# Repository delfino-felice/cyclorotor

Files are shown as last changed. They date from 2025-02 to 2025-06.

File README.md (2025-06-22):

# cyclocopter

This project aims to build a tricopter powered by two cyclorotors and one traditional propeller. Yaw control is managed through a servo mechanism that adjusts the orientation of the third motor. The primary goal is to explore alternative propulsion technologies for small UAVs by integrating cycloidal rotor mechanics into a simplified multicopter design.

The vehicle is almost entirely 3D-printed, excluding standard components such as motors, screws, and wiring. Lightweight PLA (LW-PLA) was selected as the primary material to minimize overall mass—critical for aerial vehicles—while standard PLA was used selectively in structural areas where greater strength and rigidity are required.

## Structure

The drone's structure is based on a carbon fiber tube with a 12 mm diameter and approximately 50 cm in length, chosen for its lightweight and rigid properties. At each end of the tube, a cyclorotor assembly is mounted using dual bearings for smooth and reliable rotation. These cyclorotors provide the primary lift and assist in directional thrust.

A 3D-printed clamp is positioned at the center of the tube, acting as the core structural node. It integrates and supports:

- The flight battery: 2700mAh 3s1p LiPo
- Power distribution board (PDB)
- Flight controller: F7
- Cyclorotor motors with a belt tensioning system (see photos)
- A pivoting mount and rotating joint for the rear motor, which consists of a traditional propeller attached to a servo-actuated joint. This setup provides additional thrust and enables yaw control (see photos).

## Electronics

The electronic subsystem provides stable power distribution, motor control, flight assistance (stabilization, altitude hold), and control signal routing. It includes:

- A LiPo battery connected to a Power Distribution Board (PDB)
- Brushless motors: two A2212 for the cyclorotors and one A2208 for the traditional propeller
- 30A ESCs to drive all motors
- An F7-based flight controller for real-time stabilization and control
- An Arduino-based radio receiver is used for manual remote operation. While it does not match the signal range of dedicated radio systems, it remains a cost-effective option for simple startup procedures and hovering tests.
- A servo for yaw control linked to the third motor mount

## Things to Do

Tasks that must be completed before MFR2025 and have already been thoroughly analyzed:

- Integration of the flight controller and radio receiver
- fly

## Future Ideas

Concepts for potential future upgrades, pending further analysis and decision:

- Autonomous flight capabilities: path following (e.g., with ArduPilot) and collision avoidance — key features for exploring future urban air mobility
- Larger or additional wings to increase lift capabilities and enable transportation of heavier payloads, potentially leading to a dedicated cargo version
- Thrust vectoring control (TVC) for the cyclorotors to unlock the full potential of this propulsion method
- Advanced linkage systems, such as the track-guided variable pitch mechanism seen in other experimental prototypes, which could simplify the addition of more blades and allow for higher rotational speeds, thus increasing thrust
- Build guide

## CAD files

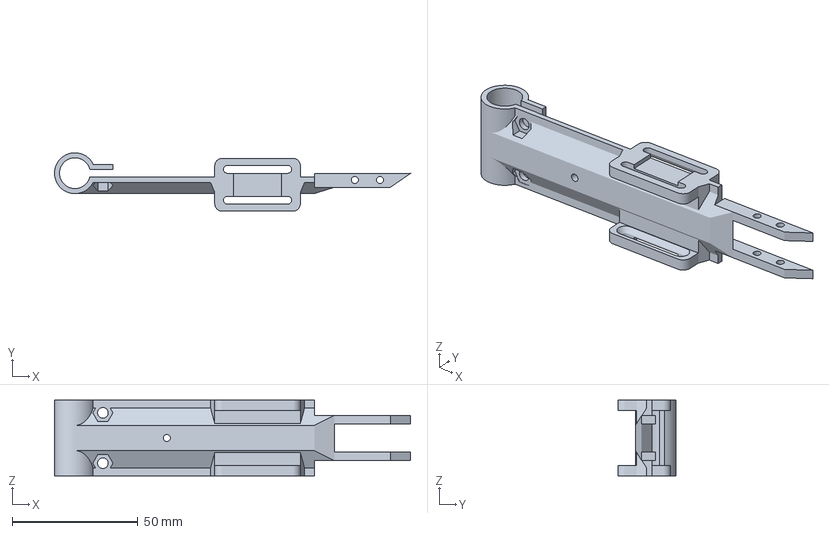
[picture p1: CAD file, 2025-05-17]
stl/3mf/main structure.3mf
141.3 x 23.2 x 30.0 mm

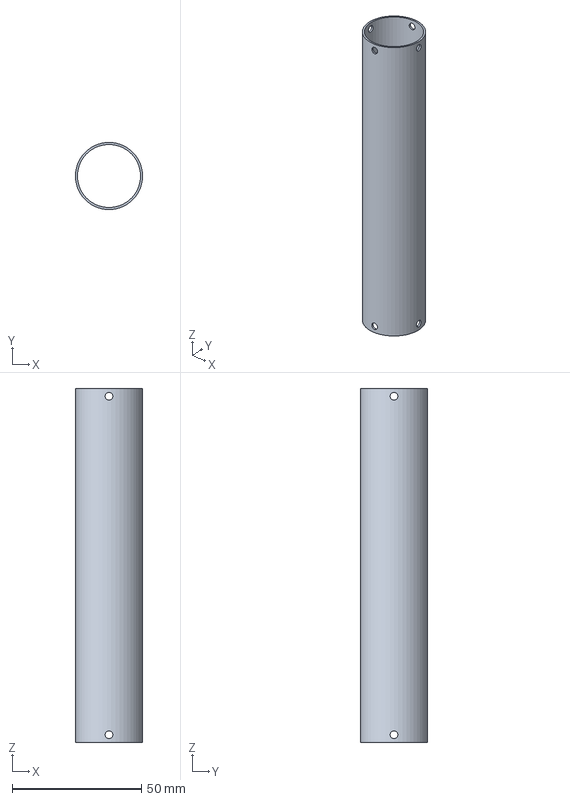
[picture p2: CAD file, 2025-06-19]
stl/3mf/tubo.3mf
26.0 x 25.9 x 137.0 mm

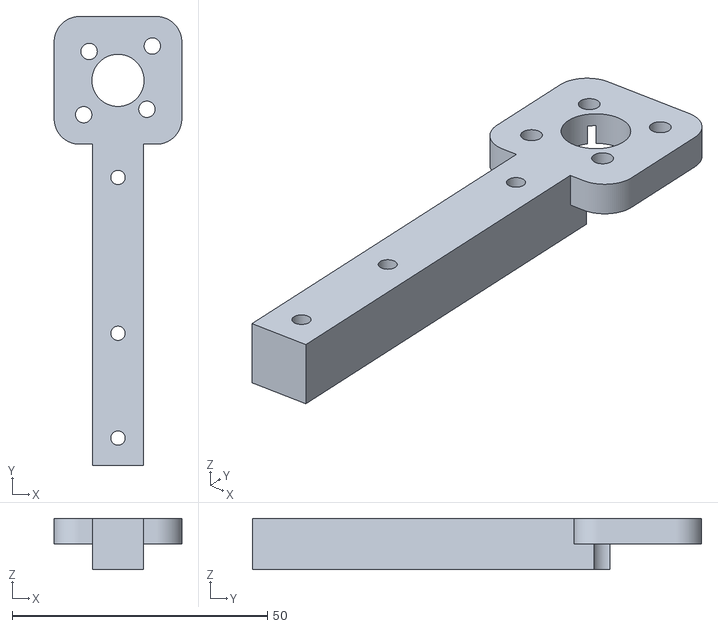
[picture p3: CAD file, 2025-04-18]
stl/giunto rotante/motor_mount.stl
25.0 x 87.9 x 10.0

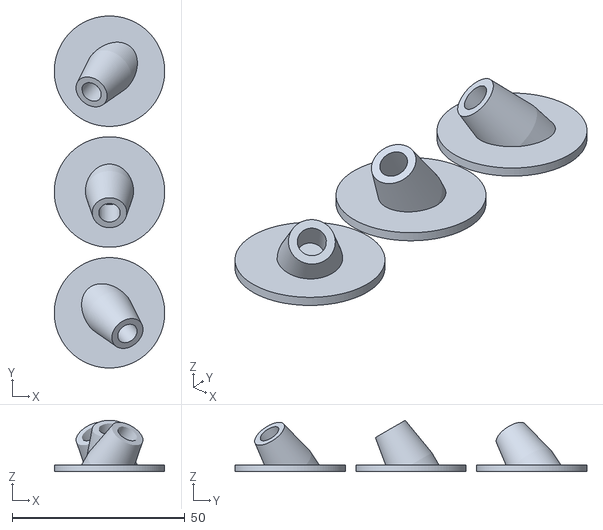
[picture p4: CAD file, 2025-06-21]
stl/piedi.stl
32.0 x 102.0 x 14.9

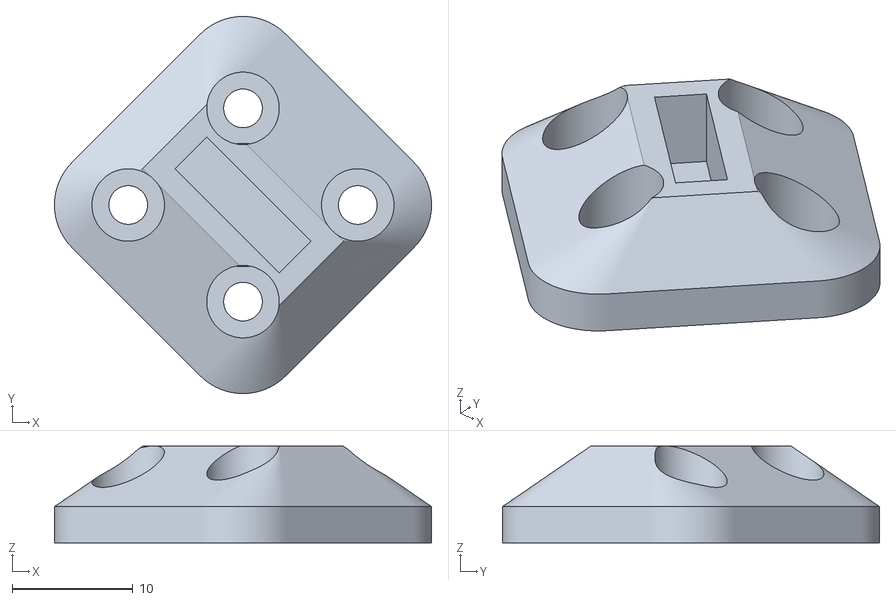
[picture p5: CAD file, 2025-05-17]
stl/test/supporto motore.stl
31.2 x 31.2 x 8.00

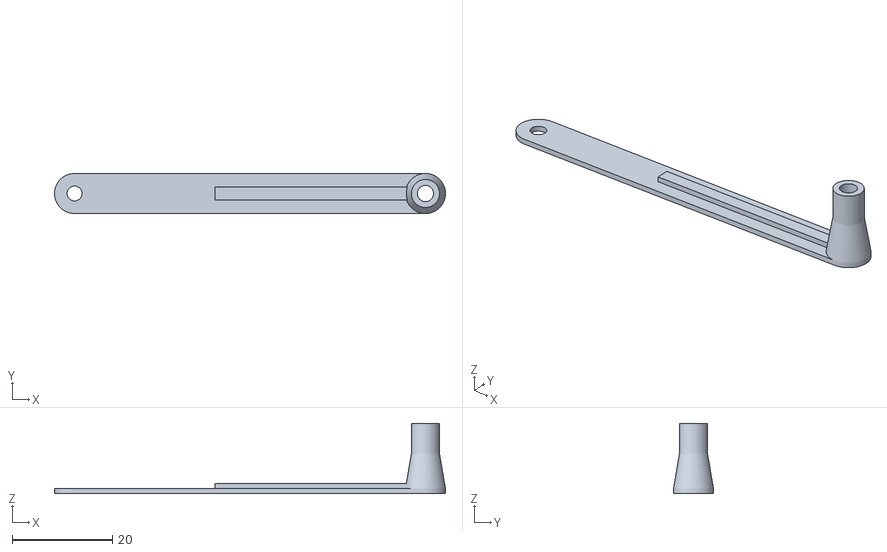
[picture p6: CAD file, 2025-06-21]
stl/braccio.stl
78.0 x 8.00 x 14.0

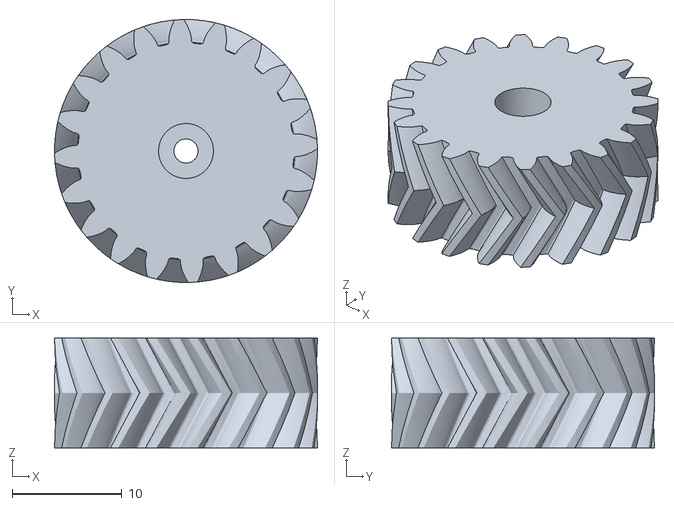
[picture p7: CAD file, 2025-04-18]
stl/giunto rotante/servo_gear.stl
24.0 x 24.0 x 10.0

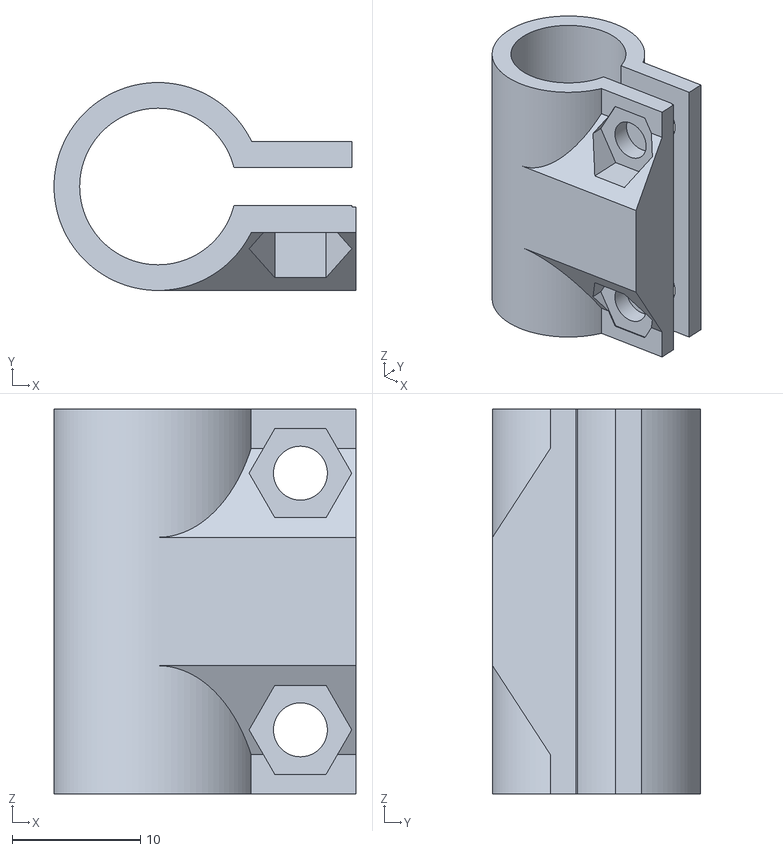
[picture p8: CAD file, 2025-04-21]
stl/test/clamp.stl
23.5 x 16.2 x 30.0

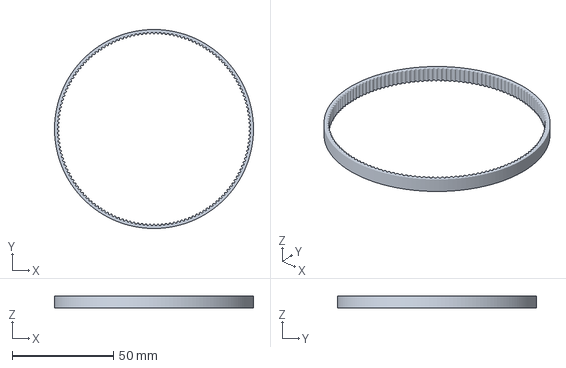
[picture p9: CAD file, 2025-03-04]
stl/3mf/belt.3mf
98.3 x 98.3 x 6.00 mm

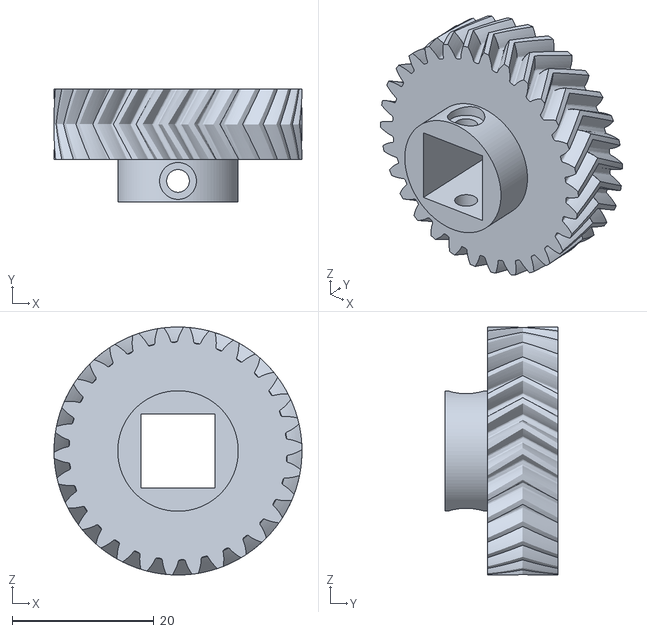
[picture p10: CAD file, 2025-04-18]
stl/giunto rotante/gear.stl
35.0 x 16.0 x 35.0

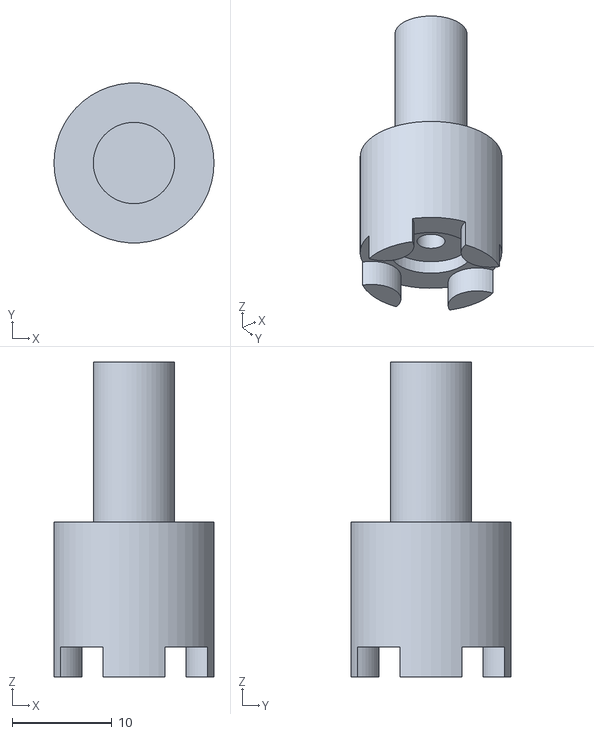
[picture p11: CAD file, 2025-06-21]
stl/ruota piccola.stl
16.0 x 16.0 x 31.5

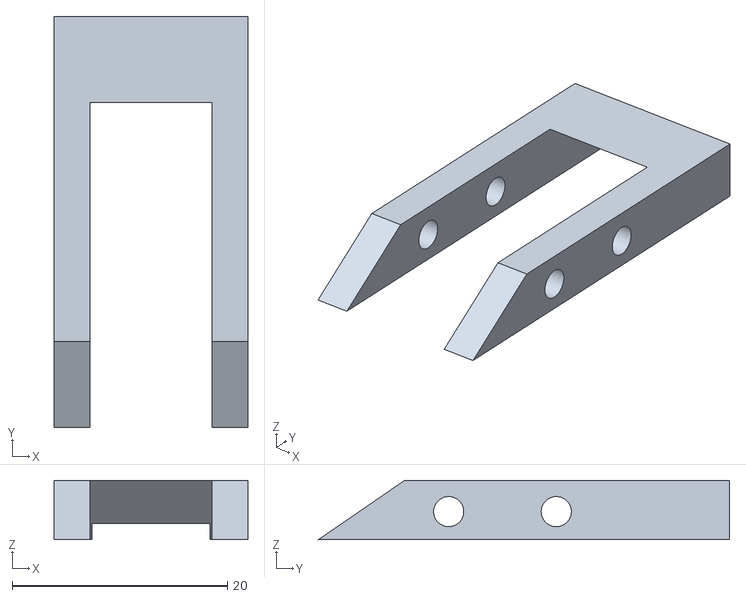
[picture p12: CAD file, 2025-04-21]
stl/test/attacco giunto.stl
18.0 x 38.2 x 5.50

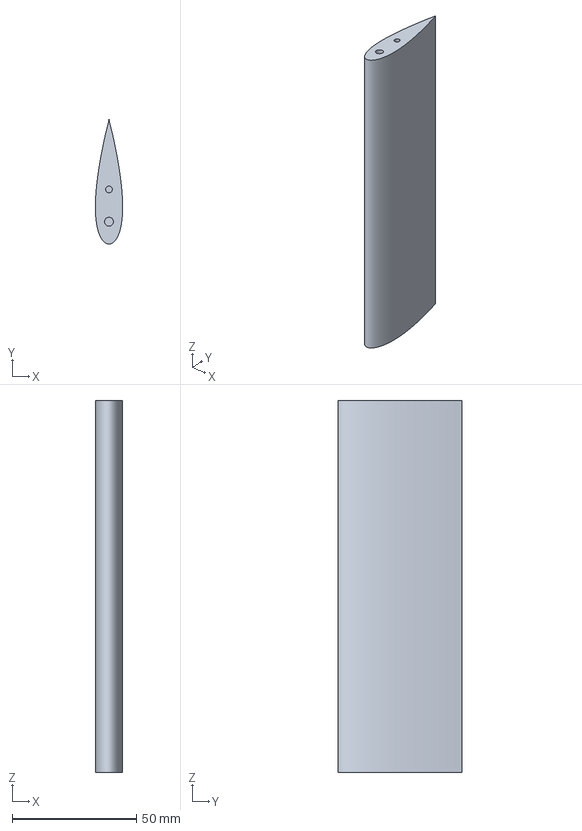
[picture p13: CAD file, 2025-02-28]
stl/3mf/wing.3mf
11.0 x 50.0 x 150.0 mm

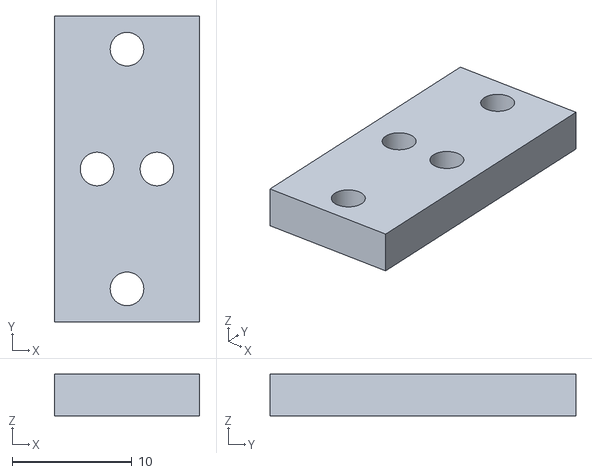
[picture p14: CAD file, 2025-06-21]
stl/asse motori.stl
12.1 x 25.5 x 3.50

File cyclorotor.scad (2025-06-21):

include <libraries/BOSL2/std.scad>
include <libraries\parametricPulley.scad>
use <libraries/NACA/ShortCuts.scad>
use <libraries/NACA/Naca4.scad>

$fn=50;

n=120; // numero denti ruota grande
or = ((n*2)/(3.14159265*2)-0.254);


module braccio() {
H=14; //altezza cilindro 
diff("remove") {
    cuboid([78,8,1], anchor=BOT, rounding=4,edges=[BACK+RIGHT,BACK+LEFT,FWD+RIGHT,FWD+LEFT])
        attach(UP,UP, align=RIGHT, inset=1) cube([45,2.5,1]);

    translate([35,0,]) cylinder(r=2.8, h=H, anchor=BOT); 
 
    translate([35,0,0]) cylinder(r=1.62, h=100, $tag="remove", center=true); // foro ala
    translate([-35,0,0]) cylinder(r=1.49, h=100, $tag="remove", center=true); // foro mozzo centrale    
    right(35) up(1) cylinder(r1=4, r2=2.8, h=7, anchor=BOT); 
}}

module clip () {

H=8;
IR=6.1;
x=7; // spessore supporti viti
difference() {
    union() {
        cylinder(h=H, r=IR+1.6, center=true); // cilindro centrale
        translate([IR+3.6,0,0]) cube([7,x,H], center=true); // supporto per viti
        yrot(90) prismoid(size1=[H,IR*2+3.2], size2=[H,x], h=IR+7.7);
    }
    union() {
        translate ([IR+3.6,0,0]) rotate ([90,0,0]) cylinder(r=1.65,h=6, center=true) {
            attach(UP,UP) cylinder(r=2.7, h=10, center=true);
            zrot(90) attach(BOT,UP) cylinder(r=3.3, h=10, $fn=6, center=true);
        }; // foro vite
        translate ([IR+3.2,0,0]) cube([10,2,200], center=true); // gioco dimensione foro centrale       
        cylinder(r=IR, h=H, center=true);
    }
}}

module distanziatore () {
tube(ir=1.8, wall=2, h=6);
}

module frame() {
l1=10;
l2=5;
w=20;
h=10;
diff("remove") {
    union() {
        // bracci della croce
        cuboid([150,10,3], rounding=5,edges=[BACK+RIGHT,BACK+LEFT,FWD+RIGHT,FWD+LEFT], anchor=BOT);
        rotate([0, 0, 90]) {
            cuboid([150,10,3], rounding=5,edges=[BACK+RIGHT,BACK+LEFT,FWD+RIGHT,FWD+LEFT], anchor=BOT);
        }
        // centro
        cylinder(r=16.2, h=10.5, anchor=BOT) // supporto cuscinetto
            attach(UP,BOT) cylinder(r1=16.2, r2=14.5, h=6) // supporto tubo
                attach(UP,UP, inside=true) cylinder(r=13.2,h=6,$tag="remove") { // foro tubo
                    // fori viti tubo
                    attach([1,1,0],BOT, overlap=.15) cylinder(r=1.6,h=1.5, $tag="remove") attach(UP,UP) cylinder(r=2.7, h=10);
                    attach([1,-1,0],BOT, overlap=.15) cylinder(r=1.6,h=1.5, $tag="remove") attach(UP,UP) cylinder(r=2.7, h=10);
                    attach([-1,1,0],BOT, overlap=.15) cylinder(r=1.6,h=1.5, $tag="remove") attach(UP,UP) cylinder(r=2.7, h=10);
                    attach([-1,-1,0],BOT, overlap=.15) cylinder(r=1.6,h=1.5, $tag="remove") attach(UP,UP) cylinder(r=2.7, h=10);
                    // conifere
                    attach(BOT,BOT) cylinder(r1=11, r2=14.15, h=2.5);
                }; 
        // interfacce supporto-bracci
        translate([15,0,3]) rotate([0,0,90]) prismoid(size1=[l1,w], size2=[l2,0], shift=[0,w/2+0], h=h, anchor=BOT+BACK);
        translate([0,15,3]) rotate([0,0,180]) prismoid(size1=[l1,w], size2=[l2,0], shift=[0,w/2+0], h=h, anchor=BOT+BACK);
        translate([-15,0,3]) rotate([0,0,270]) prismoid(size1=[l1,w], size2=[l2,0], shift=[0,w/2+0], h=h, anchor=BOT+BACK);
        translate([0,-15,3]) rotate([0,0,0]) prismoid(size1=[l1,w], size2=[l2,0], shift=[0,w/2+0], h=h, anchor=BOT+BACK);

    }
    tag("remove") {
        // fori viti ali
        translate([70,0,0]) cylinder(r=2.2, h=10, center=true); 
        translate([-70,0,0]) cylinder(r=2.2, h=10, center=true); 
        translate([0,70,0]) cylinder(r=2.2, h=10, center=true); 
        translate([0,-70,0]) cylinder(r=2.2, h=10, center=true); 
        // supporto cuscinetto
        cylinder(r=14.15, h=8, anchor=BOT);
        cylinder(r=11, h=100, center=true);
        // fori viti ingranaggio
        translate([or-8,0,0]) cylinder(r=1.4, h=100, center=true);
        translate([-(or-8),0,0]) cylinder(r=1.4, h=100, center=true);
        translate([0,or-8,0]) cylinder(r=1.4, h=100, center=true);
        translate([0,-(or-8),0]) cylinder(r=1.4, h=100, center=true);
    }    
}
echo(str("or = ", or));
}

module tubo() {
h=136;  
diff("remove") {
tube(od=26, wall=0.8, h=h);
up(h/2-3) cylinder(r=1.5, h=100, orient=FWD, center=true, $tag="remove");
up(h/2-3) cylinder(r=1.5, h=100, orient=LEFT, center=true, $tag="remove");

down(h/2-3) cylinder(r=1.5, h=100, orient=FWD, center=true, $tag="remove");
down(h/2-3) cylinder(r=1.5, h=100, orient=LEFT, center=true, $tag="remove");

}}

module ruota_grande() {    
h=7;
gear(number_of_teeth=n, profile=12, motor_shaft_diameter=(or*2)-8, belt_retainer=1, retainer_height_p=1.5, belt_idler=1, idler_height_p=1.5,base_height=0,base_diameter=17.4,flange_option=0);
// attacchi viti
difference() {
    union() {
        translate([or-7,0,0]) rotate([0,0,0]) cuboid([9,8,3], rounding=2.2,edges=[BACK+RIGHT,BACK+LEFT,FWD+RIGHT,FWD+LEFT], anchor=BOT);
        translate([-(or-7),0,0]) rotate([0,0,0]) cuboid([9,8,3], rounding=2.2,edges=[BACK+RIGHT,BACK+LEFT,FWD+RIGHT,FWD+LEFT], anchor=BOT);
        translate([0,or-7,0]) rotate([0,0,90]) cuboid([9,8,3], rounding=2.2,edges=[BACK+RIGHT,BACK+LEFT,FWD+RIGHT,FWD+LEFT], anchor=BOT);
        translate([0,-(or-7),0]) rotate([0,0,90]) cuboid([9,8,3], rounding=2.2,edges=[BACK+RIGHT,BACK+LEFT,FWD+RIGHT,FWD+LEFT], anchor=BOT);
    }
    union() {
        translate([or-8,0,0]) cylinder(r=1.6, h=100, center=true);
        translate([-(or-8),0,0]) cylinder(r=1.6, h=100, center=true);
        translate([0,or-8,0]) cylinder(r=1.6, h=100, center=true);
        translate([0,-(or-8),0]) cylinder(r=1.6, h=100, center=true);
    }
}}

module ruota_piccola() {
s=8; // raggio cilindrico negativo esterno
diff("remove"){
cylinder(r=4.07, h=16, anchor=BOT);
cylinder(r=s, h=12.5, anchor=UP){
    attach(BOT,UP, inside=true) cylinder(r=4.6, h=1.5)
        attach(BOT,BOT) cylinder(r=1.58, h=15);

    attach(BOT,UP) fwd(8.5) cylinder(r=3.3, h=3);
    attach(BOT,UP) back(8.5) cylinder(r=3.3, h=3);
    attach(BOT,UP) left(8.5) cylinder(r=3.3, h=3);
    attach(BOT,UP) right(8.5) cylinder(r=3.3, h=3);

};
tube(ir=s, wall=20, h=100, $tag="remove");
}}

module supporto_bracci() {
H=6;
R1=1.3;
R2=6.1;
D=9.5;
x=7; // spessore supporti viti
diff("remove") {
    rotate([0,90,0]) prismoid(size1=[H,(R2+1.6)*2], size2=[H,(R1+1.6)*2], h=D) { // interspazio
        position(UP) rotate([0,90,0]) cylinder(r=R1+1.6, h=H, center=true) // cilindro minore
            attach(BOT,BOT, inside=true) cylinder(r=R1, h=H, $tag="remove", center=true); // foro minore
        position(DOWN) rotate([0,90,0]) cylinder(r=R2+1.6, h=H, center=true)  // cilindro maggiore
            attach(UP,BOT, inside=true) cylinder(r=R2, h=H-0.5, $tag="remove"); // foro maggiore con bordo
    }
    translate([-(R2+3.6),0,0]) cube([7,x,H], center=true); // supporto per viti        
    yrot(-90) prismoid(size1=[H,R2*2+3.2], size2=[H,x], h=R2+7.7);


    tag("remove") {
        cylinder(r=R2-0.7, h=H+1, center=true); // foro maggiore
        translate ([-R2-3.6,0,0]) rotate ([90,0,0]) cylinder(r=1.65,h=6, center=true) {
            attach(UP,UP) cylinder(r=2.7, h=10, center=true);
            attach(BOT,UP) cylinder(r=3.3, h=10, $fn=6, center=true);
        }; // foro vite 
        translate([-(R2+3.6),0,0]) cube([10,2,100], center=true); // gioco viti        
    }

}}

module wing() {

difference() {
    airfoil(naca = 0022, L = 50, N=1000, h = 150, open = false); 
    union() {
        translate([9,0,0]) cylinder(r=1.8, h=24, center=true);
        translate([22,0,0]) cylinder(r=1.35, h=24, center=true);

        translate([9,0,150]) cylinder(r=1.8, h=24, center=true);
        translate([22,0,150]) cylinder(r=1.35, h=24, center=true);
    }    
}}

// module call
braccio();
//clip();
//distanziatore();
//frame();
//ruota_grande();
//ruota_piccola();
//supporto_bracci();
//wing();
//tubo();

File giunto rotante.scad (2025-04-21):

include <libraries/BOSL2/std.scad>
include <libraries/BOSL2/gears.scad>

// TO DO //
// ruota leggermente più basso dal motore
// controllare fori per cuscinetto accanto al motore


$fn=100;

module servo_gear() {
circ_pitch=3;
teeth=20;
diff ("remove") {
import("STL/11_Gripper_gear_v4.stl");
spur_gear(
    circ_pitch=circ_pitch, teeth=teeth, thickness=10, shaft_diam=5,
    helical=30, herringbone=true, slices=5, anchor=BOT
);

echo(str("pitch_radius = ", pitch_radius(circ_pitch, teeth,30)));
echo(str("outer_radius = ", outer_radius(circ_pitch, teeth,30)));

}}

module motor_mount () {
legth=55;

diff("remove") {
zrot(45) {
cuboid([25,25,5], anchor=BOT, spin=45, rounding=5, edges=[FRONT+LEFT,FRONT+RIGHT,BACK+LEFT,BACK+RIGHT]);
translate([-3.8,3.8,0]) cube([10,legth+15,10], anchor=FRONT+BOT, spin=45);
tag("remove") {
    fwd(8) cylinder(r=1.6, h=2, anchor=BOT) attach(UP,BOT) cylinder(r=3, h=10);
    back(8) cylinder(r=1.6, h=2, anchor=BOT) attach(UP,BOT) cylinder(r=3, h=10);
    left(9.5) cylinder(r=1.6, h=2, anchor=BOT) attach(UP,BOT) cylinder(r=3, h=10);
    right(9.5) cylinder(r=1.6, h=2, anchor=BOT) attach(UP,BOT) cylinder(r=3, h=10);
    cylinder(r=5.1, h=100, center=true);
}}
left(19) cylinder(r=1.4, h=10,anchor=BOT, $tag="remove");
left(49.5) cylinder(r=1.4, h=10,anchor=BOT, $tag="remove");
left(70) cylinder(r=1.4, h=10,anchor=BOT, $tag="remove");
}}

module giunto() {
thickness=4;
ir=16.1;
d=26;
diff("remove") {
tube(ir=ir, wall=thickness, h=d, orient=FWD) {
    attach(UP, BOT) cylinder(r=ir+thickness, h=10, orient=FWD, $tag="bau") {
        cyl(r=ir, h=10, $tag="remove");
        attach(UP,UP, inside=true) tube(ir=ir-4, or=ir+thickness, h=1, anchor=BOT, $tag="keep");
        
        attach([1,0.5,0], FRONT, overlap=2) cube([33,15,10], $tag="bau") {
            attach(BACK,FRONT,inside=true) cube([22.8,12.2,10], $tag="remove") {
                attach(UP,UP, align=LEFT, inside=true) right(3.5) cylinder(r=0.9, h=10, $tag="remove");                      
                attach(UP,UP, align=RIGHT, inside=true) left(3.5) cylinder(r=0.9, h=10, $tag="remove");
            };
        };
        
        attach([-1,0.5,0], FRONT, overlap=2) cube([33,15,10], $tag="bau") {
            attach(BACK,FRONT,inside=true) cube([22.8,12.2,10], $tag="remove") {
                attach(UP,UP, align=LEFT, inside=true) right(3.5) cylinder(r=0.9, h=10, $tag="remove");                      
                attach(UP,UP, align=RIGHT, inside=true) left(3.5) cylinder(r=0.9, h=10, $tag="remove");
            };
        };
    };
    attach(BOT, UP) cylinder(r=ir+thickness, h=10, orient=FWD, $tag="bau") {
        cyl(r=ir, h=10, $tag="remove");
        attach(UP,UP, inside=true) tube(ir=ir-4, or=ir+thickness, h=1, anchor=BOT, $tag="keep");
    };

    attach (BACK,FRONT, inside=true) cube([(ir+thickness)*2,30,d]);
    
    diff ("e") {
        attach (FRONT, BOT, overlap=2) prismoid(size1=[15,d+20], size2=[15,d-5], h=9) {
            attach(LEFT, LEFT, inside=true) fwd(2) right(2) prismoid(size1=[2,d+22], size2=[2,d-3], h=9, $tag="e");
            attach(RIGHT, LEFT, inside=true) fwd(2) left(2) prismoid(size1=[2,d+22], size2=[2,d-3], h=9, $tag="e");

            fwd(5) cylinder(r=1.4, h=15, orient=LEFT, anchor=CENTRE, $tag="e");
            back(5) cylinder(r=1.4, h=15, orient=LEFT, anchor=CENTRE, $tag="e");

        };
    }

};

cylinder(r=18, h=26, orient=BACK, anchor=CENTRE, $tag="remove");    
}
}

module bearing () {
diff("remove") {

import("STL/Bearing_6002_V02_tolMin (base).stl");
cylinder(r=8.5, h=15);
cube([10.4,10.4,100],anchor=BOT, $tag="remove");
translate([-5,0,12]) cylinder(r=1.6, h=2, orient=LEFT,$tag="remove" )
    attach(UP,UP) cylinder(r=2.6, h=10);
translate([5,0,12]) cylinder(r=1.6, h=2, orient=RIGHT,$tag="remove" )
    attach(UP,UP) cylinder(r=2.6, h=10);
}
}

module gear() {
circ_pitch=3;
teeth=30;
diff("remove") {
spur_gear(
    circ_pitch=circ_pitch, teeth=teeth, thickness=10, shaft_diam=8.5,
    helical=30, herringbone=true, slices=5, anchor=BOT
);
;
echo(str("pitch_radius = ", pitch_radius(circ_pitch, teeth,30)));
echo(str("outer_radius = ", outer_radius(circ_pitch, teeth,30)));
cylinder(r=8.5, h=16);
cube([10.4,10.4,100],anchor=BOT, $tag="remove");
translate([-5,0,13]) cylinder(r=1.6, h=2, orient=LEFT,$tag="remove" )
    attach(UP,UP) cylinder(r=2.6, h=10);
translate([5,0,13]) cylinder(r=1.6, h=2, orient=RIGHT,$tag="remove" )
    attach(UP,UP) cylinder(r=2.6, h=10);
}}


  giunto();
//  up(5) zrot(90) right(45) xrot(180) motor_mount();
//  xrot(90) up(13) zrot(90) bearing();
//  xrot(-90) up(14) zrot(90) bearing();
//  xrot(90) down(8.5) zrot(90) gear();
//  servo_gear();

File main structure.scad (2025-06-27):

include <libraries/BOSL2/std.scad>
include <libraries/BOSL2/skin.scad>
$fn=100;


l=95;
h=7.1;
h_piano=2;
W_braccio=36;
d_motori=72.5;
ir=6.1;
L=20;
d_supporto=10.5;

module main() {
diff("remove") {

prismoid(size1=[l,10], size2=[l,W_braccio], h=h) {
    attach(UP,UP, inside=true) cube([l,W_braccio,h_piano], $tag="bau"); 


    d=30.5/2;
    attach(UP,UP) left(d_supporto) cube([W_braccio,W_braccio,2]);
    left(d_supporto) translate([d,d,0]) cylinder(r=1.4, h=100, center=true, $tag="remove");
    left(d_supporto) translate([-d,d,0]) cylinder(r=1.4, h=100, center=true, $tag="remove");
    left(d_supporto) translate([d,-d,0]) cylinder(r=1.4, h=100, center=true, $tag="remove");
    left(d_supporto) translate([-d,-d,0]) cylinder(r=1.4, h=100, center=true, $tag="remove");

    attach(RIGHT,FRONT, align=BOT) prismoid(size1=[10,0], size2=[18.7325,8], h=3.1, shift=[0,4]);

    right(d_motori-(l/2)) attach(UP,BOT, inside=true) cuboid([L,14,h], $tag="bau") { // cubo base
        attach([FRONT,BACK], BOT) prismoid(size1=[L,h], size2=[L+15,h], h=8, $tag="remove")
            attach(UP,UP) cube([L+15,h,100]); // spazio per supporti motore
        attach(UP,UP, overlap=1.5) prismoid(size1=[L+6,14], size2=[L+20,14], h=5, $tag="bau"); // prisma di rinforzo

        up(1.75) cube([L,14,3.8], $tag="remove", anchor=CENTRE) // spazio albero motore
            cube([L,3.2,6.8], $tag="remove", anchor=CENTRE) // spazio vite
                attach([UP,BOT],UP) cube([L+3,6,10], $tag="remove", anchor=CENTRE); // spazio bullone/testa
    };


};
left(l/2) back(W_braccio/2) cylinder(r=ir+2, h=W_braccio, anchor=BOT+FRONT, orient=FRONT) {
    attach(UP,UP,inside=true) cylinder(r=ir, h=W_braccio);
    attach(RIGHT,LEFT, overlap=5) right(1.5) cube([12,9,W_braccio], $tag="bau") {
        attach(BACK,UP, align=RIGHT, inset=2.5, inside=true) fwd(11) cylinder(r=2.1, h=9, $tag="remove")
            attach(BOT,UP) cylinder(r=4, h=10, $fn=6);
        attach(BACK,UP, align=RIGHT, inset=2.5, inside=true) back(11) cylinder(r=2.1, h=9, $tag="remove")
            attach(BOT,UP) cylinder(r=4, h=10, $fn=6);
    };
    attach(RIGHT,LEFT, overlap=3) cube([12,2,W_braccio], $tag="remove");
};


}}

module attacco_giunto() {
diff ("remove") {
zrot(90) right(2) prismoid(size1=[38.2,18.7325], size2=[30.2,18.7325], h=5.5, shift=[4,0]);
fwd(5) up(2.6) cylinder(r=1.4, h=25, orient=LEFT, anchor=CENTRE, $tag="remove");
back(5) up(2.6) cylinder(r=1.4, h=25, orient=LEFT, anchor=CENTRE, $tag="remove");
zrot(90) right(2) prismoid(size1=[38.2,11.3], size2=[22.2,11.3], h=5.5, $tag="remove");
down(3.5) cube([11,50,5], anchor=BOT, $tag="remove");

}}

module supporto () {
diff("remove") {
width = 30;
lenght = 44;
a=30;
cuboid([lenght,width,5], rounding=3, edges=[BACK+LEFT,FRONT+LEFT], anchor=UP, spin=90) 
    attach(BOT,UP) cuboid([lenght+10,width+10,50], $tag="remove"); 
fwd(lenght/2-2) xrot(a) cylinder(r1=7, r2=5, h=12, anchor=BOT) {
    attach(UP,UP, inside=true) cylinder(r=3.1, h=10);
    attach(BOT,UP) cylinder(r=7, h=10, center=true);
};
back(lenght/2-2) right(width/2-2) yrot(a) xrot(-a) cylinder(r1=7, r2=5, h=12, anchor=BOT) {
    attach(UP,UP, inside=true) cylinder(r=3.1, h=10);
    attach(BOT,UP) cylinder(r=7, h=10, center=true);
};
back(lenght/2-2) left(width/2-2) yrot(-a) xrot(-a) cylinder(r1=7, r2=5, h=12, anchor=BOT) {
    attach(UP,UP, inside=true) cylinder(r=3.1, h=10);
    attach(BOT,UP) cylinder(r=7, h=10, center=true);
};
    d_fori=0;
    fwd(d_fori) cylinder(r=1.4, h=100, center=true, $tag="remove");
    fwd(d_fori + 7) cylinder(r=1.4, h=100, center=true, $tag="remove");
    fwd(d_fori - 7) cylinder(r=1.4, h=100, center=true, $tag="remove");

}}

module motor_mount () {
diff("remove") {
cuboid([25,25,3], anchor=BOT, spin=45, rounding=5, edges=[FRONT+LEFT,FRONT+RIGHT,BACK+LEFT,BACK+RIGHT]) 
    attach(UP,BOT) skin([rect([25, 25], rounding=5), rect([7.5,16], center=true)], z=[0,5], slices=50, method="tangent")
        attach(UP,BOT, inside=true) cube([3.7,12.1,5.5], $tag="remove")
            attach(LEFT,UP) cylinder(r=1.6, h=2, $tag="remove") attach(BOT,UP) cylinder(r=2.6, h=10, $tag="remove");

tag("remove") {
    fwd(8) cylinder(r=1.6, h=2, anchor=BOT) attach(UP,BOT) cylinder(r=3, h=100);
    back(8) cylinder(r=1.6, h=2, anchor=BOT) attach(UP,BOT) cylinder(r=3, h=100);
    left(9.5) cylinder(r=1.6, h=2, anchor=BOT) attach(UP,BOT) cylinder(r=3, h=100);
    right(9.5) cylinder(r=1.6, h=2, anchor=BOT) attach(UP,BOT) cylinder(r=3, h=100);
    cylinder(r=5.1, h=2, anchor=BOT);
}
}}

module battery_mount () {
diff("remove") {
cube([22,51,4], anchor=BOT) 
    attach(BOT, BOT, align=[FRONT, BACK], inside=true) left(5) cube([38,8,50], $tag="bau")
        attach(BACK,BACK, align=UP, inset=7, inside=true) cube([27.2,8,34.2], $tag="remove");

d_fori=0;
left(d_fori) cylinder(r=1.6, h=3, anchor=BOT, $tag="remove") attach(UP,UP) cylinder(r=2.6, h=3, center=true, $tag="remove");
left(d_fori + 7) cylinder(r=1.6, h=3, anchor=BOT, $tag="remove") attach(UP,UP) cylinder(r=2.6, h=3, center=true, $tag="remove");
left(d_fori - 7) cylinder(r=1.6, h=3, anchor=BOT, $tag="remove") attach(UP,UP) cylinder(r=2.6, h=3, center=true, $tag="remove");
}}

module arduino_mount () {
d=30.5/2;

diff("remove") {
cuboid([113,82,3], anchor=BOT, rounding=2, edges=[FRONT+LEFT,FRONT+RIGHT,BACK+LEFT,BACK+RIGHT]);

translate([35, 0, 0]) {
translate([d,d,0]) cylinder(r=3.5, h=7, anchor=UP, $tag="bau") attach(BOT,UP, inside=true) cylinder(r=1.6, h=7, $tag="remove") attach(BOT,UP) cylinder(r=2.6, h=7, $tag="remove");   
translate([-d,d,0]) cylinder(r=3.5, h=7, anchor=UP, $tag="bau") attach(BOT,UP, inside=true) cylinder(r=1.6, h=7, $tag="remove") attach(BOT,UP) cylinder(r=2.6, h=7, $tag="remove");   
translate([d,-d,0]) cylinder(r=3.5, h=7, anchor=UP, $tag="bau") attach(BOT,UP, inside=true) cylinder(r=1.6, h=7, $tag="remove") attach(BOT,UP) cylinder(r=2.6, h=7, $tag="remove");   
translate([-d,-d,0]) cylinder(r=3.5, h=7, anchor=UP, $tag="bau") attach(BOT,UP, inside=true) cylinder(r=1.6, h=7, $tag="remove") attach(BOT,UP) cylinder(r=2.6, h=7, $tag="remove");   
}

}}

module asse_motori () {
diff("remove") {

cube([12.1,25.5,3.5], anchor=BOT);
left(2.5) cylinder(r=1.4, h=10,$tag="remove");
right(2.5) cylinder(r=1.4, h=10,$tag="remove");
fwd(10) cylinder(r=1.4, h=10,$tag="remove");
back(10) cylinder(r=1.4, h=10,$tag="remove");
}}

module supporto_giroscopio () {
diff("remove") {
    cube ([20,10,5]) {
        attach(FWD,UP, align=UP) cube([20,10,4])
            attach(FWD,LEFT, align=UP) cube([4,20,25]);
        left(7.5) fwd(3) cylinder(r=1.4, h=10, $tag="remove", center=true);
        right(7.5) fwd(3) cylinder(r=1.4, h=10, $tag="remove", center=true);
    };
}}


module piedi() {
diff("remove") {
cylinder(r=16, h=2) {
    attach(UP,BOT) xrot(30) cylinder(r1=7,r2=5,h=12) {
        attach(UP,UP, inside=true) cylinder(r=3.1, h=10);
        attach(BOT,UP) cylinder(r=7, h=10, center=true);
    };
    attach(BOT,BOT) cylinder(r=20, h=100, $tag="remove");
}

fwd(35) cylinder(r=16, h=2) {
    attach(UP,BOT) yrot(30) xrot(30) cylinder(r1=7,r2=5,h=12) {
        attach(UP,UP, inside=true) cylinder(r=3.1, h=10);
        attach(BOT,UP) cylinder(r=7, h=10, center=true);
    };
    attach(BOT,BOT) cylinder(r=20, h=100, $tag="remove");
}

back(35) cylinder(r=16, h=2) {
    attach(UP,BOT) yrot(-30) xrot(30) cylinder(r1=7,r2=5,h=12) {
        attach(UP,UP, inside=true) cylinder(r=3.1, h=10);
        attach(BOT,UP) cylinder(r=7, h=10, center=true);
    };
    attach(BOT,BOT) cylinder(r=20, h=100, $tag="remove");
}
}}
//supporto();
 right(l/2+21.1) zrot(90) yrot(180) down(8.6) attacco_giunto();
 main();
//motor_mount();
//asse_motori();
//zrot(90) battery_mount();
//arduino_mount();
//supporto_giroscopio();
//piedi();

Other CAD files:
stl/giunto rotante/giunto.stl
stl/3mf/frame.3mf
stl/distanziatore.stl
stl/3mf/ruota grande.3mf
stl/11_Gripper_gear_v4.stl
stl/3mf/braricentro angolare.3mf
stl/arduino_mount.stl
stl/battery mount.stl
stl/clip.stl
stl/frame.stl
stl/main structure.stl
stl/ruota grande.stl
stl/supporto bracci.stl
stl/supporto giroscopio.stl
stl/supporto motore.stl
stl/supporto.stl
stl/tubo.stl
stl/wing.stl

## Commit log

2025-01-24 riorganizzazione e nuova clip
    [belt.scad, clip.scad, clip.stl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]
2025-01-25 nuovo braccetto
    [braccetto.scad, braccietto.stl, braricentro angolare.scad]
2025-01-25 baricentro riprogettato
    [braricentro angolare.scad, braricentro angolare.stl, supporto motore.scad]
2025-01-25 aggiunta di distanziatore
    [baricentro angolare.scad, cyclorotor.scad, distanziatore.scad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]
2025-01-25 arrotondando gli spigoli
    [cyclorotor.scad, frame.scad, supporto motore.scad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]
2025-01-28 nuova ruota piccola
    [ruota piccola.scad, ruota piccola.stl, ruota piccolina.scad]
2025-01-30 clean up
    [baricentro angolare.scad, baricentro angolare.stl, braricentro angolare.stl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]
2025-01-30 ruota piccola più grande
    [ruota piccola.scad, ruota piccola.stl]
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2025-02-08 nuovo frammento e braccio più corto
    [braccetto.scad, braccio (lungo).stl, braccio.scad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]
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2025-02-17 tolleranza ridotta e base più spessa
    [supporto bracci.scad, supporto bracci.stl]
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2025-02-17 bracci viti più tozzi, fori maggiorati
    [ruota grande.scad]
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2025-02-25 libreria per le pulegge modificata e nuovi ingranaggi
    [ruota grande.scad, ruota grande.stl, ruota piccola.scad]
2025-02-28 supporto viti più rigido
    [baricentro angolare.scad, baricentro angolare.stl, clip.scad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]
2025-02-28 aggiunta di un piccolo bordo a baricentro angolare per migliorare la stabilità
    [baricentro angolare.scad, baricentro angolare.stl]
2025-02-28 supporto bracci più sottile
    [supporto bracci.scad, supporto bracci.stl, wing.3mf]
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2025-03-18 distanza viti clip ridotta in modo da bloccare il bullone
    [baricentro angolare.scad, baricentro angolare.stl, clip.scad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]
2025-03-23 nuovo sistema di collegamento
    [braccio.scad, braccio1.stl, braccio2.stl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]
2025-03-29 nuovo blocco del bullone
    [baricentro angolare.scad, baricentro angolare.stl]
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2025-04-12 braccio con dimensioni corrette ed test struttura principale
    [braccio.scad, braccio.stl, main structure.scad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]
2025-04-12 pulizia e nuovi test per la struttura principale
    [belt.3mf, braricentro angolare.3mf, frame (old).stl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]
2025-04-13 giunto e supporto motore modificati
    [Hygro stand.3mf, main structure.scad, main structure.stl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]
2025-04-14 aggiunta dei supporti per i due servo e rispettivi ingranaggi
    [11_Gripper_gear_v4.stl, main structure.scad, servo_mount.stl]
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2025-04-18 nuovi denti per le ruote
    [gear.stl, main structure.scad, motor_mount.stl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]
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2025-04-23 nuovo attacco per i supporti dei motori
    [main structure.scad]
2025-04-24 unione della struttura principale al supporto dei motori
    [main structure.scad, main structure.stl, supporto motore.scad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]
2025-04-24 spazio per albero motore
    [main structure.scad, main structure.stl]
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2025-05-17 redesign of motor mount
    [main structure.3mf, main structure.scad, supporto motore.stl]
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2025-05-17 supporto motore più leggero e nuova struttura principale
    [main structure.scad, supporto motore.stl]
2025-05-24 aggiunta supporto gambe e miglioramenti
    [asse motori.stl, main structure.scad, main structure.stl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]
2025-05-25 aggiunto supoorto per la batteria
    [battery mount.stl, main structure.scad]
2025-05-25 struttura principale più resistente
    [main structure.scad]
2025-05-25 nuovo aggangio tra i supporti dei motori e l'asse
    [main structure.scad]
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2025-05-27 aggiunta del supporto per l'elettronica
    [PDB_mount.stl, main structure.scad]
2025-05-28 pdb_mount spostato lateralmente e aggiunta di una risoluzione temporanea per la struttura principale
    [PDB_mount.stl, fix_main_structure.scad, fix_main_structure.stl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]
2025-05-28 un po' di rendering
    [arduino_mount.stl, main structure.scad, supporto motore.stl]
2025-05-28 ruota piccola più alta di 1.7mm
    [ruota piccola.scad, ruota piccola.stl]
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2025-06-14 ruota piccola più grande: h+=.5, t+=5
    [ruota piccola.scad, ruota piccola.stl]
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2025-06-14 supporto bracci più robusto
    [clip.stl, supporto bracci.scad, supporto bracci.stl]
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2025-06-16 Updated support thickness and adjusted hole dimensions for improved fit
    [clip.scad, clip.stl]
2025-06-16 Increased height of the clip and adjusted support dimensions for improved stability
    [clip.scad, clip.stl]
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2025-06-16 Remove unused modules and clean up code structure
    [braccio.scad, clip.scad, cyclorotor.scad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]
2025-06-17 Refactor clip and distanziatore modules for improved structure and stability; update STL files for new dimensions
    [clip.stl, cyclorotor.scad, distanziatore.stl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]
2025-06-17 Adjust dimensions in asse_motori module for improved fit; update STL file accordingly
    [asse motori.stl, main structure.scad]
2025-06-18 Adjust braccio module dimensions and rounding for improved geometry; update corresponding STL file
    [braccio.stl, cyclorotor.scad]
2025-06-18 improved structure for braccio; stl generated
    [braccio.stl, cyclorotor.scad]
2025-06-19 Refactor frame module for improved structure and stability; update corresponding STL file
    [cyclorotor.scad, frame.stl]
2025-06-19 added tube for new frame; stl
    [cyclorotor.scad, tubo.stl]
2025-06-20 Refactor ruota_piccola module for improved geometry; update corresponding STL file
    [cyclorotor.scad, ruota piccola.stl]
2025-06-21 Refactor ruota_piccola module for improved dimensions; update corresponding STL file
    [cyclorotor.scad, ruota piccola.stl]
2025-06-21 Update dimensions in asse_motori; regenerate corresponding STL file
    [asse motori.stl, main structure.scad]
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2025-06-27 new motor and screw mounting structure
    [main structure.scad]
